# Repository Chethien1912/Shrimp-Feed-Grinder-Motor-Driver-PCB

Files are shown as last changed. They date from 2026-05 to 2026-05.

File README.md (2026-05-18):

# Shrimp-Feed-Grinder-Motor-Driver-PCB
Board dùng vi điều khiển STM32F0 làm trung tâm điều khiển.

STM32 xử lý các tín hiệu vào/ra, điều khiển PWM, relay, MOSFET công suất và LED 7 đoạn.

Phần driver sử dụng MOSFET công suất IRF540N để điều khiển thắng điện từ DC.

Tín hiệu điều khiển MOSFET được cách ly bằng opto PC817, giúp bảo vệ vi điều khiển khỏi nhiễu và xung áp từ tải công suất.

Mạch có diode và zener bảo vệ MOSFET khi đóng/ngắt cuộn thắng điện từ.

Board điều khiển động cơ 220VAC công suất 0.5HP thông qua relay và mạch công suất.

Khối relay dùng để điều khiển các trạng thái chạy, dừng, thắng và chuyển mạch động cơ.

Mạch khởi động mềm sử dụng nguyên lý TRIAC - DIAC, giúp giảm dòng khởi động ban đầu cho động cơ.

Điều khiển tốc độ hoặc mức công suất bằng tín hiệu PWM từ vi điều khiển.

Hiển thị trạng thái hoạt động bằng LED 7 đoạn 4 digit.

LED 7 đoạn được điều khiển qua IC TM1637, chỉ cần hai chân giao tiếp CLK và DIO.

Khối nguồn tạo các mức điện áp cần thiết như 12V, 3.3V và 55VDC.

Nguồn 3.3V cấp cho STM32 và IC hiển thị.

Nguồn 12V cấp cho relay và mạch điều khiển phụ.

Nguồn 55VDC dùng cho phần thắng điện từ.

Tổng thể board tập trung vào điều khiển phần cứng cho động cơ, gồm điều khiển PWM, thắng điện từ, khởi động mềm và hiển thị trạng thái.

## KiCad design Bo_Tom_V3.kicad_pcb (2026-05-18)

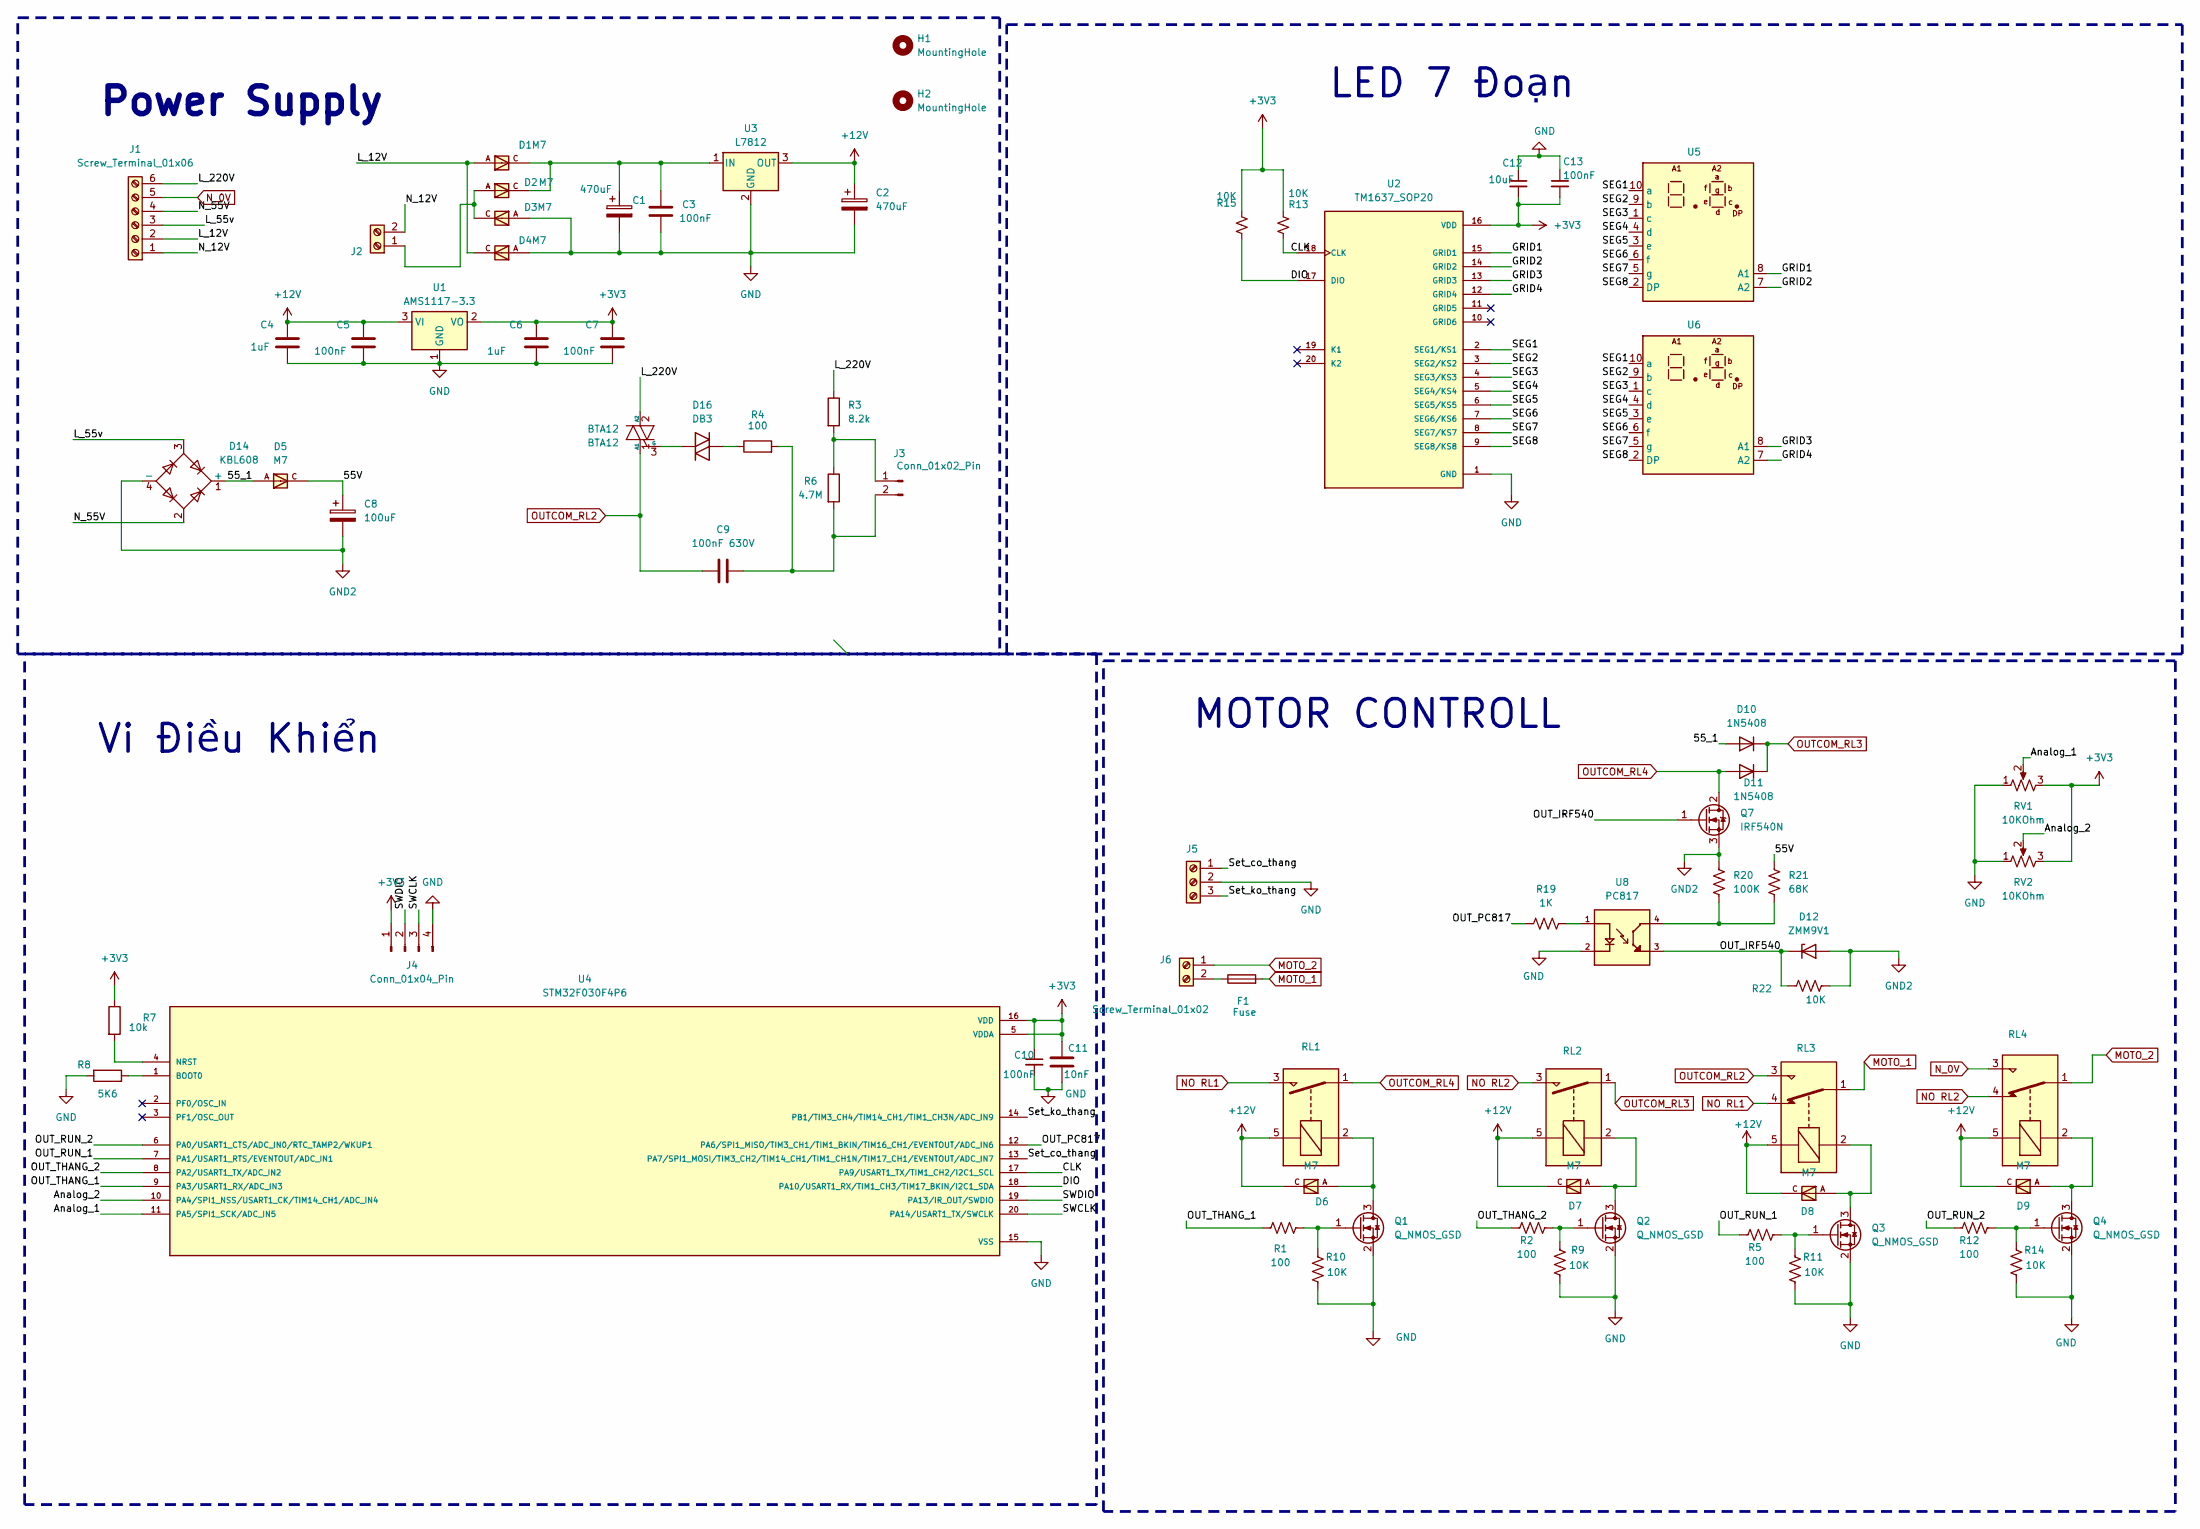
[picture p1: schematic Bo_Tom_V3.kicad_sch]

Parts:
BTA12: BTA12; TO-220-3_Vertical
C1, C2: 470uF; C_Radial_D8.0mm_H11.5mm_P3.50mm
C3, C5, C7, C13: 100nF; C_0603_1608Metric
C4, C6: 1uF; C_0603_1608Metric
C8: 100uF; C_Radial_D10.0mm_H16.0mm_P5.00mm
C9: 100nF 630V; C_Rect_L11.5mm_W4.5mm_P10.00mm_MKT
C10: 100nF; C_0603
C11: 10nF; C_0603_1608Metric
C12: 10uF; C_0603_1608Metric
D1, D2, D3, D4, D5, D6, D7, D8, D9: M7; DIOM505270X240; MPN M7
D10, D11: 1N5408; D_DO-201AD_P15.24mm_Horizontal
D12: ZMM9V1; diode_ZMM
D14: KBL608; KLB608
D16: DB3; D_DO-35_SOD27_P7.62mm_Horizontal
F1: Fuse; Fuse_Bourns_MF-RG300
H1, H2: MountingHole; Hole_3mm
J1: Screw_Terminal_01x06; TE_826576-6_1x06_P3.96mm_Vertical
J2, J6: Screw_Terminal_01x02; TE_826576-2_1x02_P3.96mm_Vertical
J3: Conn_01x02_Pin; Conn-Vert-THT-2P-2.54mm-S2B_XH_SM4_TB
J4: Conn_01x04_Pin; PinHeader_1x04_P2.54mm_Vertical
J5: Screw_Terminal_01x03; Conn-Vert-THT-3P-2.54mm-S3B_XH_SM4_TB
Q1, Q2, Q3, Q4: Q_NMOS_GSD; SOT-23
Q7: IRF540N; TO-220-3_Vertical
R1, R2, R5, R12: 100; R_0603_1608Metric
R3: 8.2k; R_0603
R4: 100; R_0603
R6: 4.7M; R_0805
R7: 10k; R_0603_1608Metric
R8: 5K6; R_0603_1608Metric
R9, R10, R11, R13, R14, R15, R22: 10K; R_0603_1608Metric
R19: 1K; R_0603_1608Metric
R20: 100K; R_0603_1608Metric
R21: 68K; R_0603_1608Metric
RL1, RL2: SANYOU_SRD_Form_A; Relay_SPST_SANYOU_SRD_Series_Form_A
RL3, RL4: SANYOU_SRD_Form_C; Relay_SPDT_SANYOU_SRD_Series_Form_C
RV1, RV2: 10KOhm; VR_WH148-3P-103
U1: AMS1117-3.3; SOT-223-3_TabPin2
U2: TM1637_SOP20; SOIC127P1035X255-20N; PARTREV V2.6
U3: L7812; TO-252-2
U4: STM32F030F4P6; SOP65P640X120-20N
U5, U6: Led 7 segment 2 digit
U8: PC817; SOIC254P975X460-4N

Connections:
+3V3: C6.1, C7.1, C10.1, C11.1, C12.2, C13.2, J4.1, R7.1, R13.2, R15.2, RV1.3, RV2.3, U1.2 (VO), U2.16 (VDD), U4.5 (VDDA), U4.16 (VDD)
+12V: C2.1, C4.1, C5.1, D6.C, D7.C, D8.C, D9.C, RL1.5, RL2.5, RL3.5, RL4.5, U1.3 (VI), U3.3 (OUT)
/55V: C8.1, D5.C, R21.2
/55_1: D5.A, D10.2 (A), D14.1 (+)
/Analog_1: RV1.2, U4.11 (PA5/SPI1_SCK/ADC_IN5)
/Analog_2: RV2.2, U4.10 (PA4/SPI1_NSS/USART1_CK/TIM14_CH1/ADC_IN4)
/CLK: R13.1, U2.18 (CLK), U4.17 (PA9/USART1_TX/TIM1_CH2/I2C1_SCL)
/DIO: R15.1, U2.17 (DIO), U4.18 (PA10/USART1_RX/TIM1_CH3/TIM17_BKIN/I2C1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)
/GRID1: U2.15 (GRID1), U5.8 (A1)
/GRID2: U2.14 (GRID2), U5.7 (A2)
/GRID3: U2.13 (GRID3), U6.8 (A1)
/GRID4: U2.12 (GRID4), U6.7 (A2)
/L_12V: D1.A, D4.C, J1.2
/L_55v: D14.3, J1.3
/L_220V: BTA12.2 (A2), J1.6, R3.1
/N_12V: J1.1, J2.2
/N_55V: D14.2, J1.4
/OUT_IRF540: D12.1 (K), Q7.1 (G), R22.2, U8.3
/OUT_PC817: R19.2, U4.12 (PA6/SPI1_MISO/TIM3_CH1/TIM1_BKIN/TIM16_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)
/OUT_RUN_1: R5.1, U4.7 (PA1/USART1_RTS/EVENTOUT/ADC_IN1)
/OUT_RUN_2: R12.1, U4.6 (PA0/USART1_CTS/ADC_IN0/RTC_TAMP2/WKUP1)
/OUT_THANG_1: R1.1, U4.9 (PA3/USART1_RX/ADC_IN3)
/OUT_THANG_2: R2.1, U4.8 (PA2/USART1_TX/ADC_IN2)
/SEG1: U2.2 (SEG1/KS1), U5.10 (a), U6.10 (a)
/SEG2: U2.3 (SEG2/KS2), U5.9 (b), U6.9 (b)
/SEG3: U2.4 (SEG3/KS3), U5.1 (c), U6.1 (c)
/SEG4: U2.5 (SEG4/KS4), U5.4 (d), U6.4 (d)
/SEG5: U2.6 (SEG5/KS5), U5.3 (e), U6.3 (e)
/SEG6: U2.7 (SEG6/KS6), U5.6 (f), U6.6 (f)
/SEG7: U2.8 (SEG7/KS7), U5.5 (g), U6.5 (g)
/SEG8: U2.9 (SEG8/KS8), U5.2 (DP), U6.2 (DP)
/SWCLK: J4.3, U4.20 (PA14/USART1_TX/SWCLK)
/SWDIO: J4.2, U4.19 (PA13/IR_OUT/SWDIO)
/Set_co_thang: J5.1, U4.13 (PA7/SPI1_MOSI/TIM3_CH2/TIM14_CH1/TIM1_C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)
/Set_ko_thang: J5.3, U4.14 (PB1/TIM3_CH4/TIM14_CH1/TIM1_CH3N/ADC_IN9)
GND: C1.2, C2.2, C3.2, C4.2, C5.2, C6.2, C7.2, C10.2, C11.2, C12.1, C13.1, D3.A, D4.A, J4.4, J5.2, Q1.2 (S), Q2.2 (S), Q3.2 (S), Q4.2 (S), R8.2, R9.1, R10.1, R11.1, R14.1, RV1.1, RV2.1, U1.1 (GND), U2.1 (GND), U3.2 (GND), U4.15 (VSS), U8.2
GND2: C8.2, D12.2 (A), D14.4 (-), Q7.3 (S), R20.2, R22.1
MOTO_1: F1.2, RL3.1
MOTO_2: J6.1, RL4.1
NO RL1: RL1.3, RL3.4
NO RL2: RL2.3, RL4.4
N_0V: J1.5, RL4.3
unnamed: BTA12.3 (G), D16.1 (K)
unnamed: D16.2 (A), R4.1
unnamed: D2.A, D3.C, J2.1
unnamed: J3.1, R3.2, R6.1
unnamed: C9.2, J3.2, R4.2, R6.2
unnamed: F1.1, J6.2
unnamed: D6.A, Q1.3 (D), RL1.2
unnamed: Q1.1 (G), R1.2, R10.2
unnamed: D7.A, Q2.3 (D), RL2.2
unnamed: Q2.1 (G), R2.2, R9.2
unnamed: D8.A, Q3.3 (D), RL3.2
unnamed: Q3.1 (G), R5.2, R11.2
unnamed: D9.A, Q4.3 (D), RL4.2
unnamed: Q4.1 (G), R12.2, R14.2
unnamed: R19.1, U8.1
unnamed: R20.1, R21.1, U8.4
unnamed: C1.1, C3.1, D1.C, D2.C, U3.1 (IN)
unnamed: R8.1, U4.1 (BOOT0)
unnamed: R7.2, U4.4 (NRST)
OUTCOM_RL2: BTA12.1 (A1), C9.1, RL3.3
OUTCOM_RL3: D10.1 (K), D11.1 (K), RL2.1
OUTCOM_RL4: D11.2 (A), Q7.2 (D), RL1.1

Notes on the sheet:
LED 7 Đoạn
MOTOR CONTROLL
Power Supply
Vi Điều Khiển

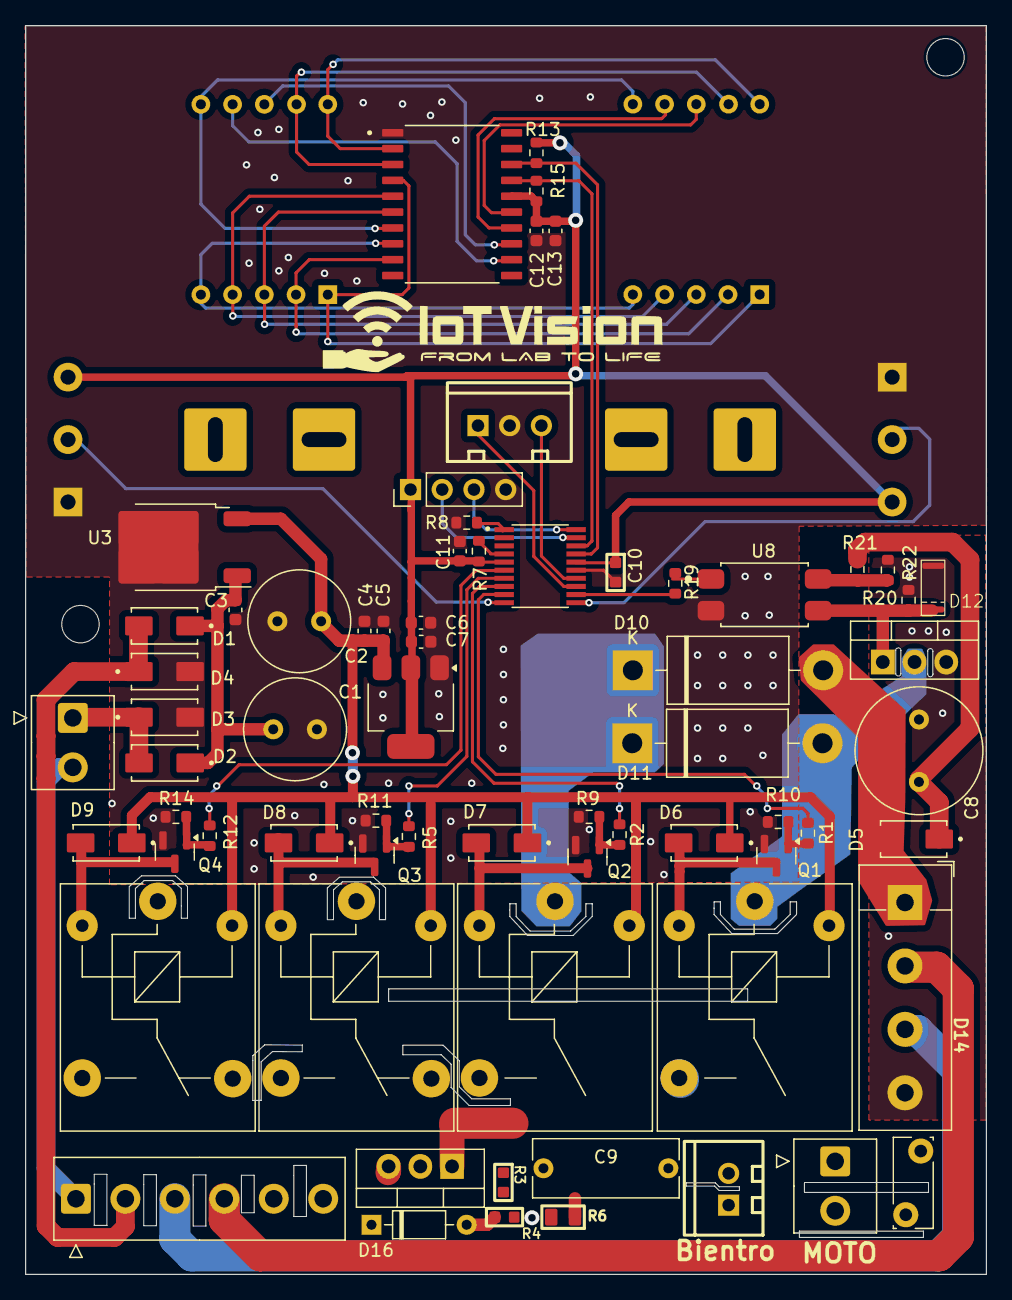
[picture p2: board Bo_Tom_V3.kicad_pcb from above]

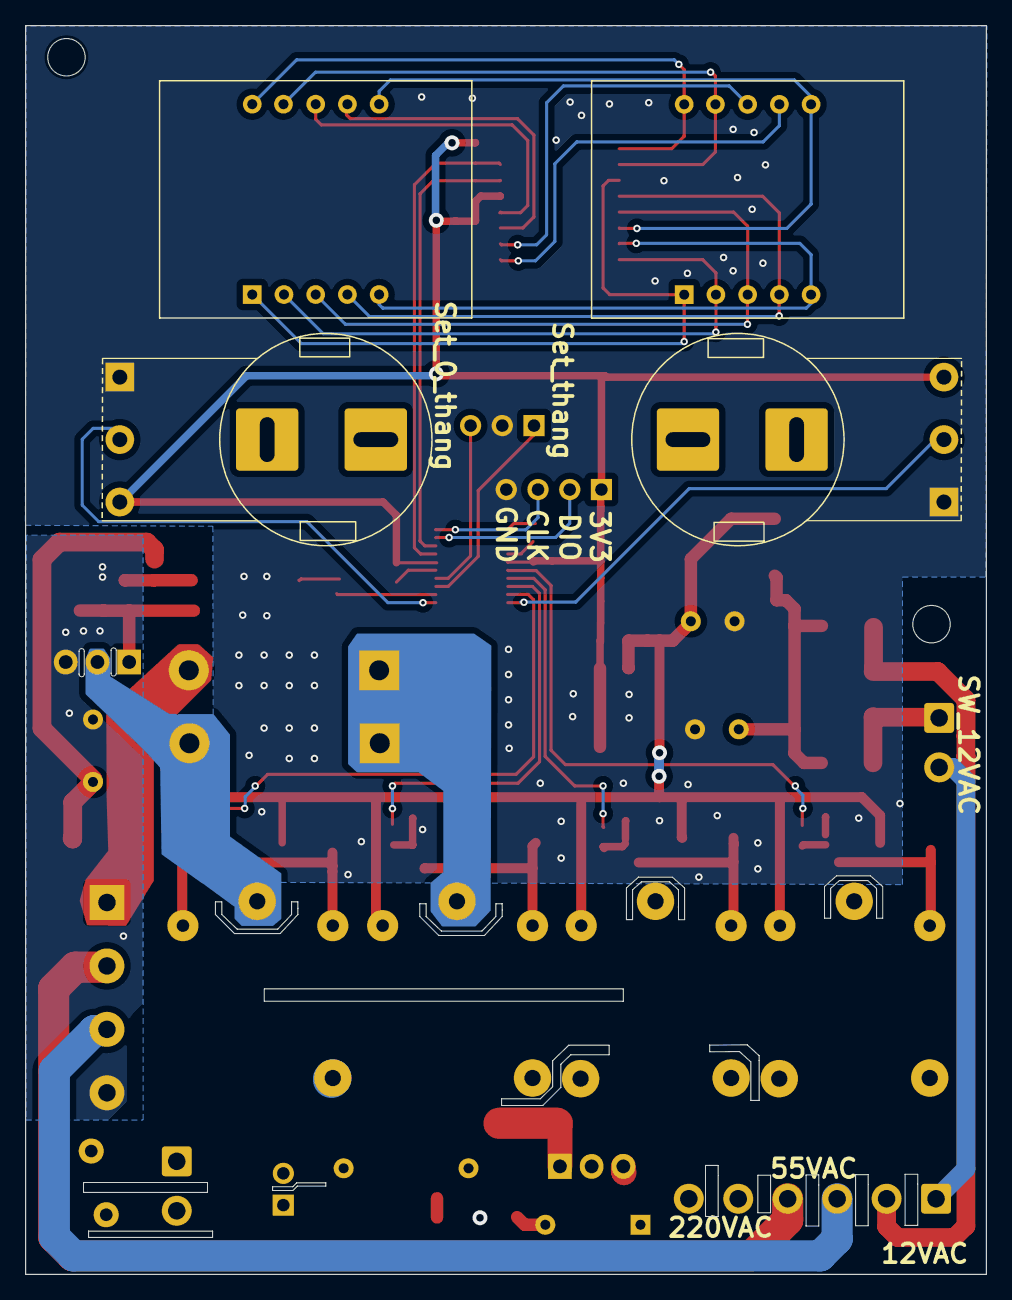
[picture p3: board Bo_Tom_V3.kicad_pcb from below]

Board: 2 copper layers, 76.9 x 100.0 mm, 74 parts (4 on the bottom side), 64 nets.
